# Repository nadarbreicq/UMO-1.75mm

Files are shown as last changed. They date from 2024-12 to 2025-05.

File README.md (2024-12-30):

# UMO-1.75mm

The Ultimaker Original, released in 2011, was my first personal 3D printer. I received it at the end of 2012 and used it without major issues until 2020. However, after that, several challenges arose:

- All my other printers used 1.75 mm filament, and I no longer wanted to manage two separate filament stocks due to insufficient throughput.
- The hotend of my Ultimaker Original started to show its age, and high-quality replacement parts were either unavailable or too expensive.
- The extruder had become almost unusable and suffered from the same supply issues as the hotend.
- Determined to keep this fantastic machine running—still capable, I’m sure, of producing quality prints—I decided to modify it to use standard Ender 3 parts and transition to 1.75 mm filament.

The goal of this repository is to share this journey with you and maybe even inspire you to try it yourself if you're interested! 😊

*This project is still a Work in Progress.*

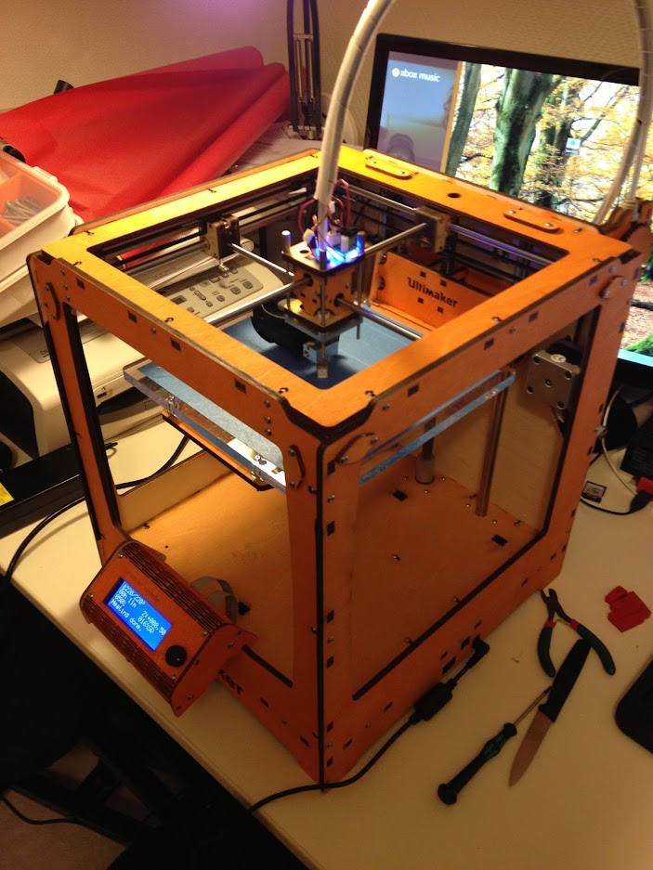
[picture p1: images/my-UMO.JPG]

*My Ultimaker Original in early 2013*

---

## **Bill of Materials (BOM)**

To modify my Ultimaker, I used the materials listed below. They are fairly standard and readily available online.

- **Extruder**: [Product Link](https://www.amazon.fr/dp/B09H6T3NNT?ref=ppx_yo2ov_dt_b_fed_asin_title&th=1)
- **HotEnd**: [Product Link](https://www.amazon.fr/dp/B09RXRQ5HM?ref=ppx_yo2ov_dt_b_fed_asin_title&th=1)

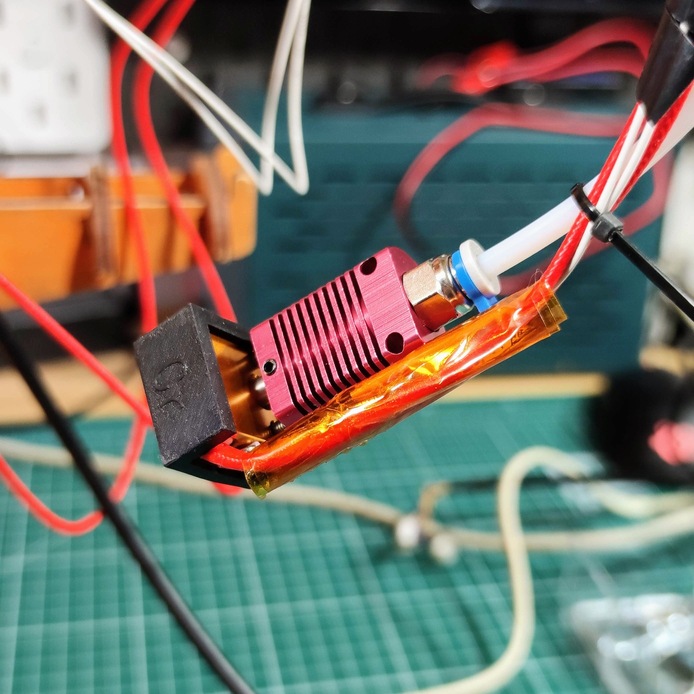
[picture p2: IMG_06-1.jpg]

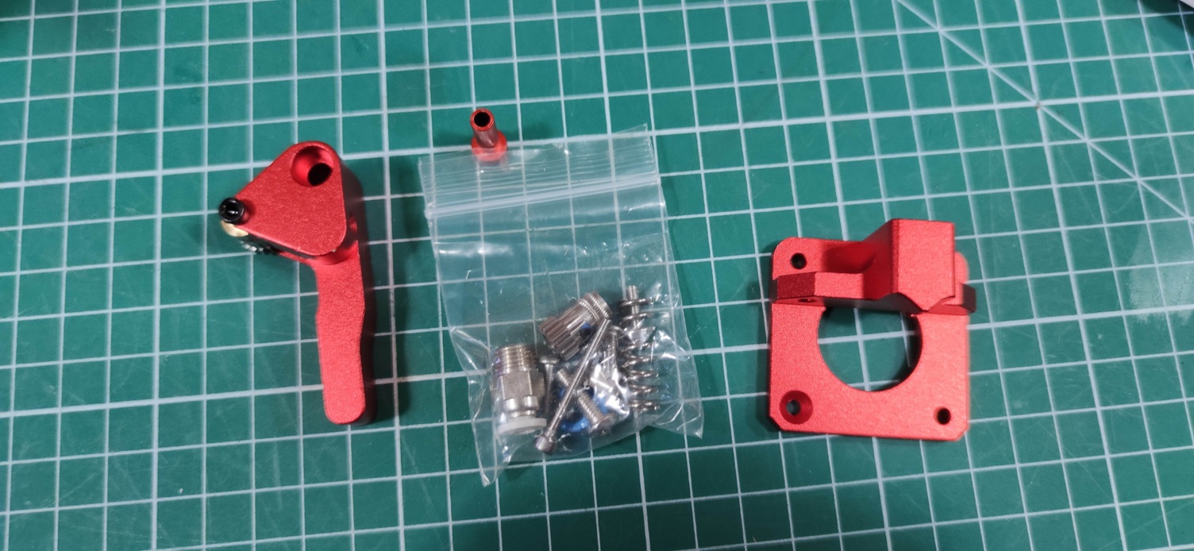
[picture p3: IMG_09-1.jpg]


You will also need a 40x40 fan to cool the print head and prevent clogging in the PTFE tube. In my case, I had a fan from an Ender 2 Pro among my spare parts, but any fan of the same type will work.

You will also need a 4.7K ohm resistor to solder onto the board (along with a soldering iron) and Molex KK254 connectors if you prefer not to cut and modify the existing sensor cable.

Regarding the resistor, it is recommended to use a high-precision resistor if you want to improve the accuracy of temperature readings. However, for initial testing, a resistor with 5% tolerance will do the job. It will be soldered to the **R23** position on the mainboard.

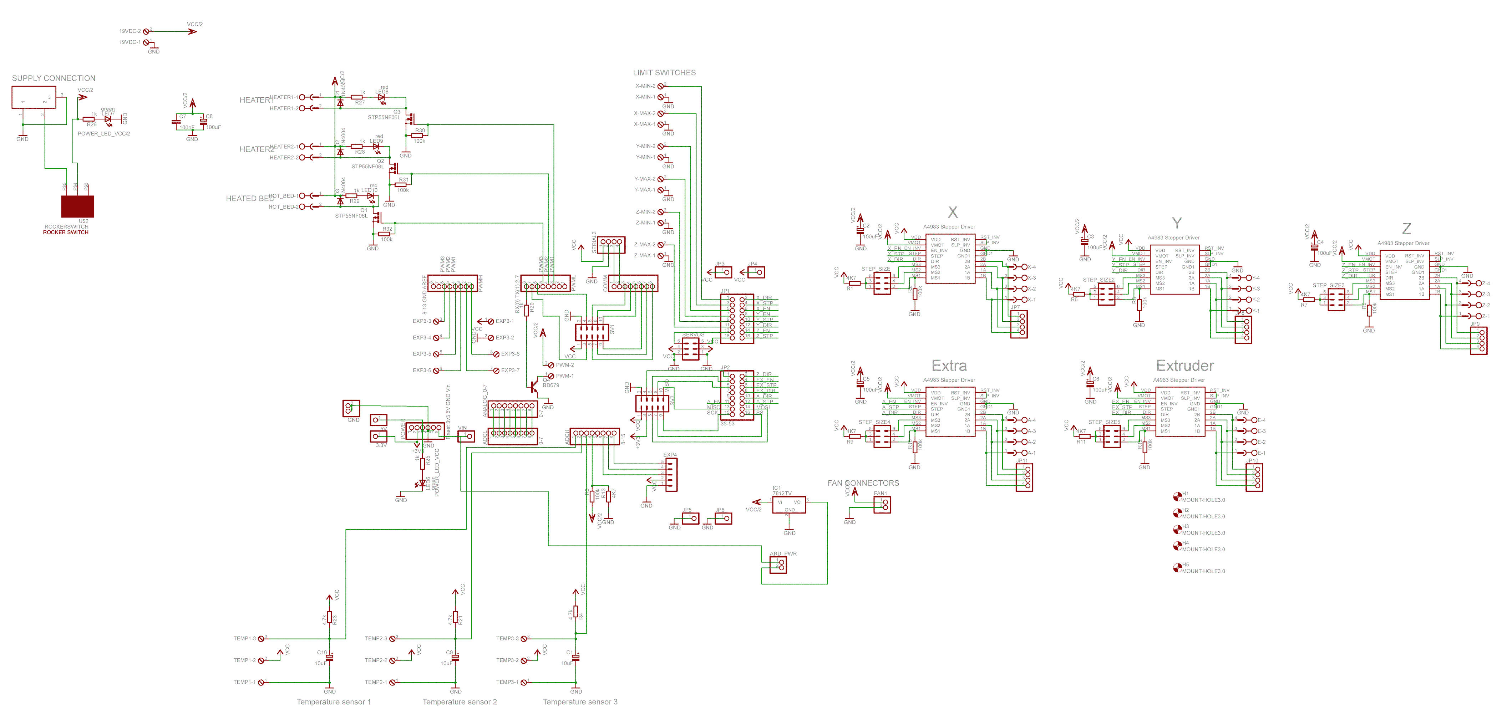
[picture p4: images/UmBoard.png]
Board Diagram


To help you, you can also take a look at the BOM from Ultimaker Repo :

- Original files from ultimaker : [Ultimaker Original BOM](https://github.com/Ultimaker/UltimakerOriginal/tree/master)

---

### **Removing the Original Print Head and Extruder**

**Note:** In my case, I had already attempted a modification of the extruder. The version I have is therefore slightly different. I’ll use this version to temporarily attach the new extruder while I design a proper *Ultimaker-style* replacement.

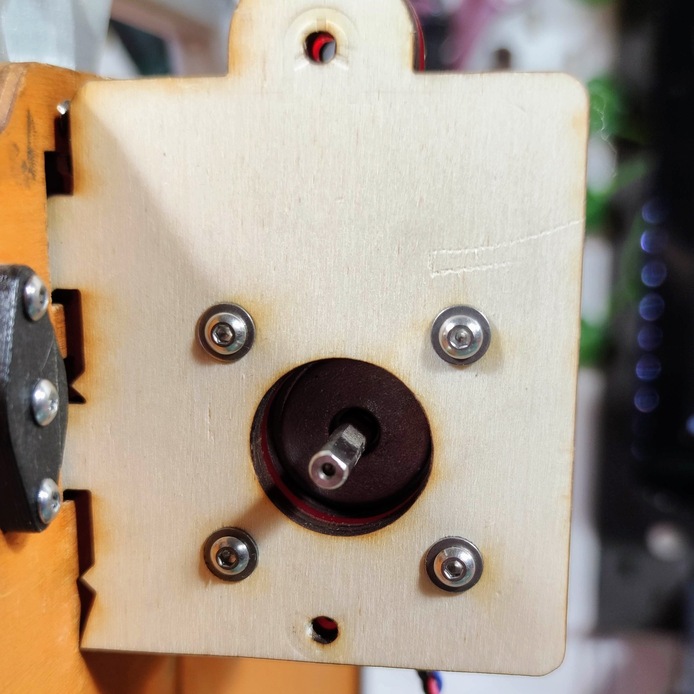
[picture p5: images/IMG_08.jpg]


#### **Steps to Disassemble the Print Head**

1. **Disconnect the heater cartridge wires**:
   
   Begin by unscrewing the connections for the heater cartridge from the mainboard. Keep the existing sensor cable intact, as it will later be repurposed for the print fan. While you're at it, disconnect the temperature sensor wires as well.

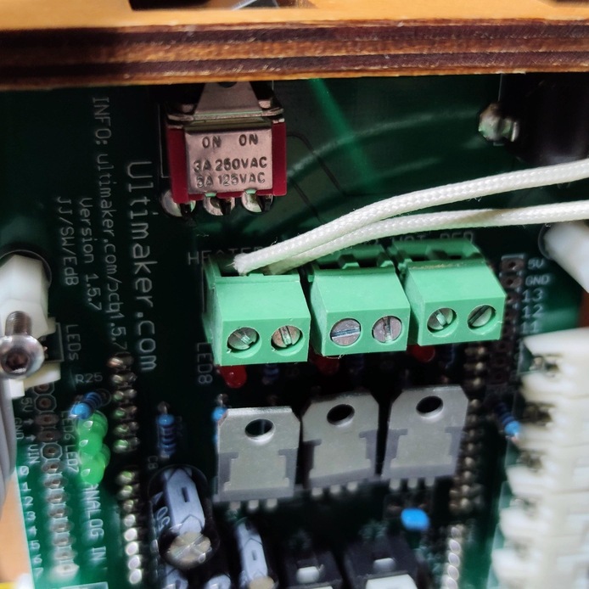
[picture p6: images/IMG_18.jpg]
  
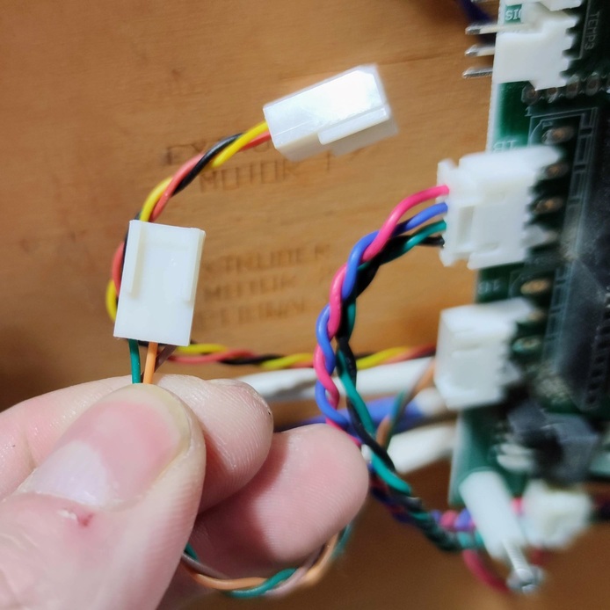
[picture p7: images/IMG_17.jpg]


2. **Remove the print head carefully**:
   
   You can now cautiously disassemble the print head. Be sure to keep all components, as you might want to reassemble them later. In my case, I decided to take everything apart individually because I wasn’t sure how the reassembly would go. Initially, I planned to reuse the original heater cartridge and sensor.  

   Unfortunately, the head was in such poor condition that this became impossible, and the head connector broke into two pieces.  

   **Pro Tip:** Try to handle the disassembly more neatly than I did! 😊

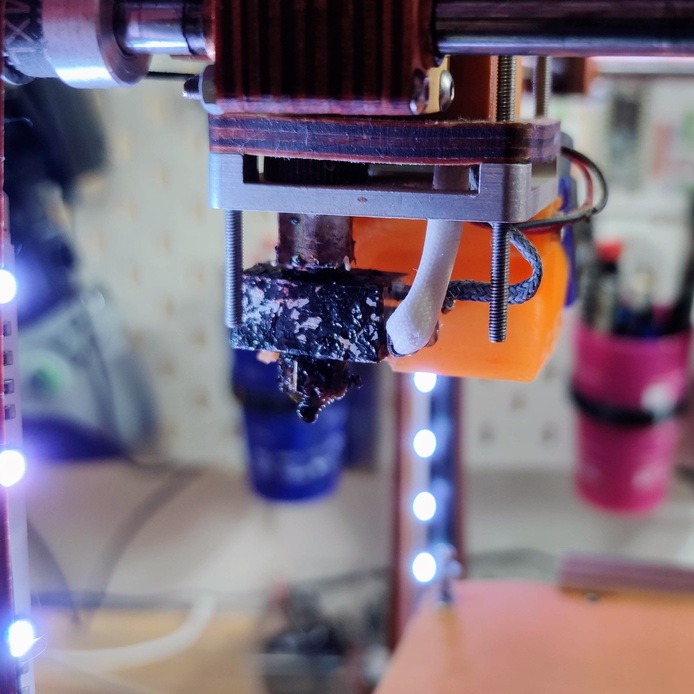
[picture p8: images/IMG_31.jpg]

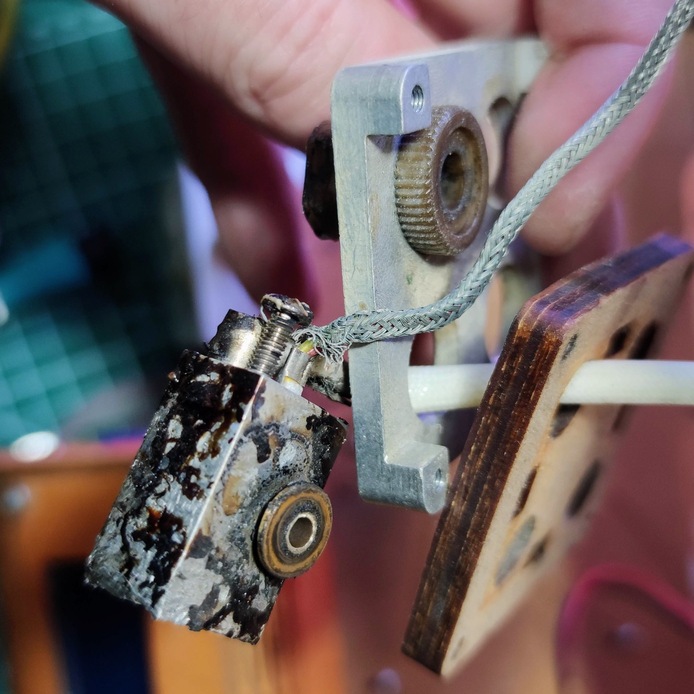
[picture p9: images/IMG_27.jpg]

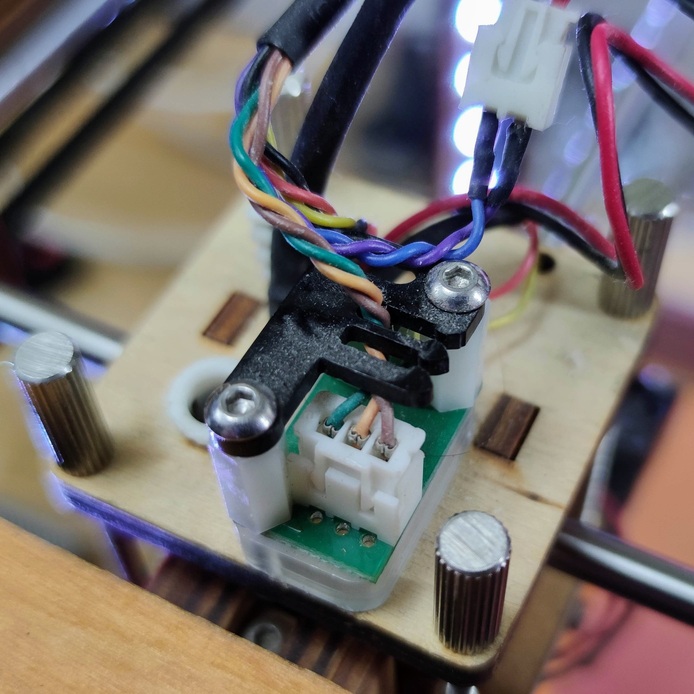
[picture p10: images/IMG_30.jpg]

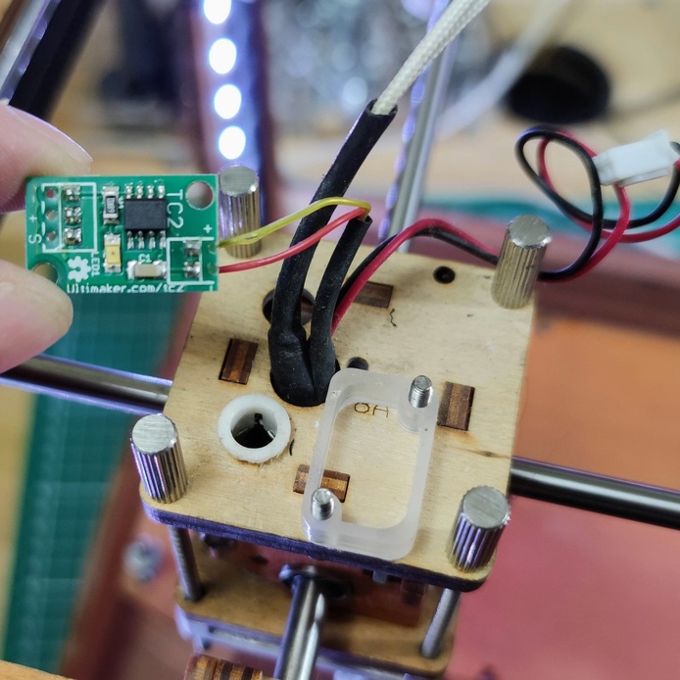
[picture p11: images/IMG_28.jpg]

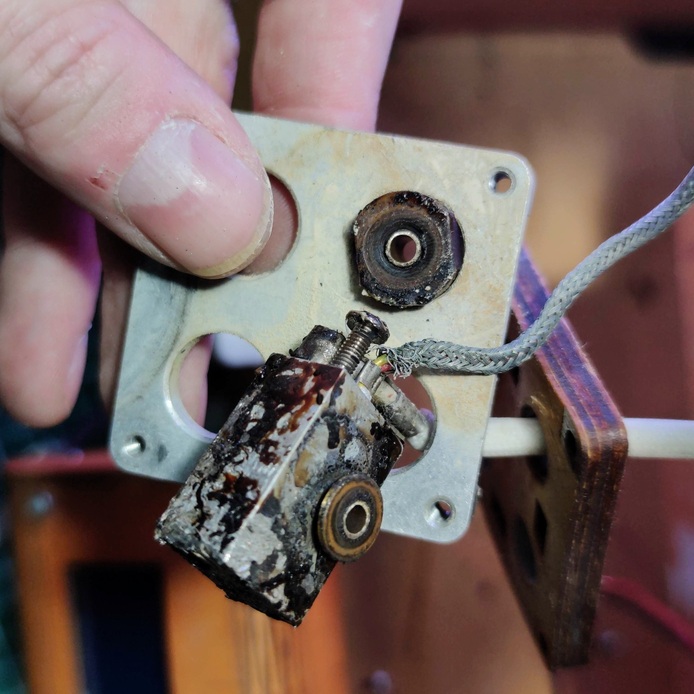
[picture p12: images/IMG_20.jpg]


#### **Assembling the Extruder**

In this case, there isn’t much to explain. The motor is compatible with the extruder, making the modification relatively straightforward. You’ll just need a mounting plate to secure the assembly. The original plate will do the job if you still have it.


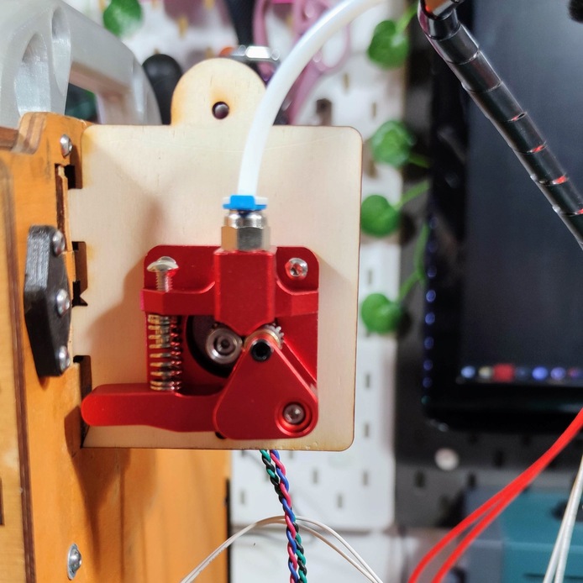
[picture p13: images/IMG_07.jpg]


#### **Cable Routing**

Now, route all the cables from the new print head through the original cable path. You should have two wires for the heater cartridge and two wires for the temperature sensor.



**Note:** I’ve always been a bit skeptical about the cable routing and cable management on this machine. While using nylon fabric sleeves for the cable bundle is a great idea, the management underneath is a real mess. 😅 I’ll have to address it properly one of these days.

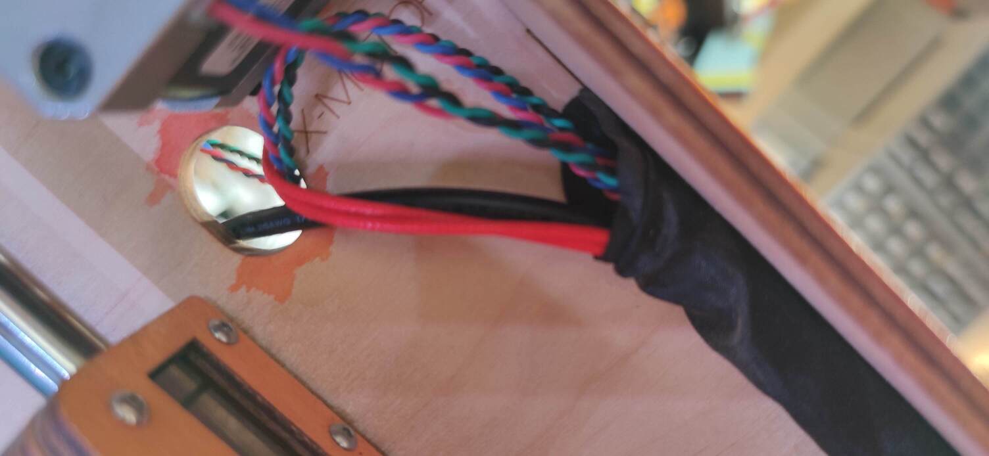
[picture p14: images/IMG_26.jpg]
  
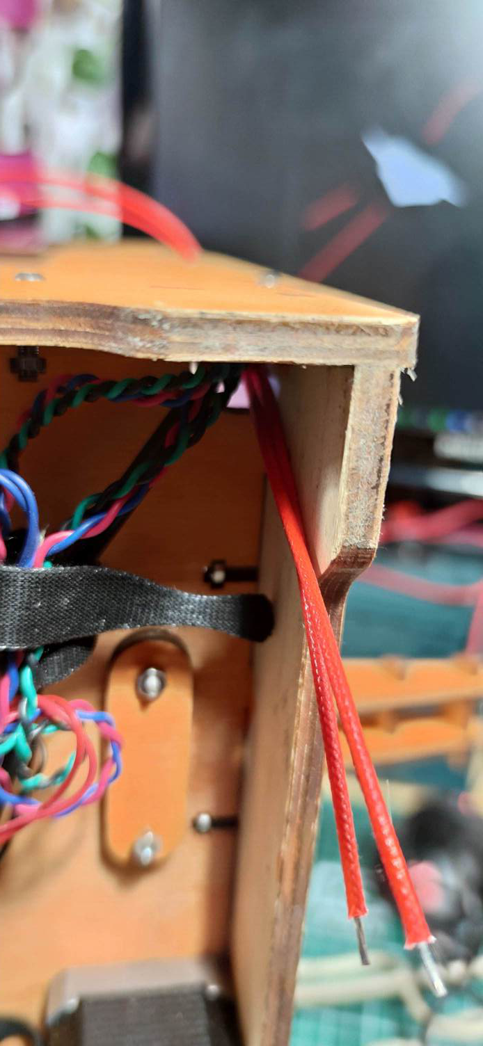
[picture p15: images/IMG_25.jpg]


Connect the heater cartridge wires to the same spot on the board as the original cartridge. The polarity doesn’t matter.  

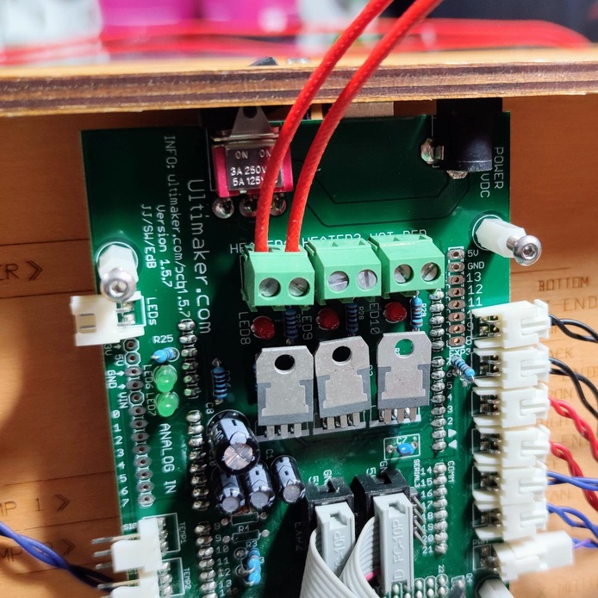
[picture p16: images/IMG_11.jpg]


#### **Soldering the 4.7K Resistor**

Next, solder the 4.7K ohm resistor. If you’re feeling ambitious, you can unplug everything, remove the board, and solder the resistor "properly" through the PCB. However, for initial testing, you can shape the resistor as shown in the photo and solder it "on the surface." This approach is fine for now, especially if you're using a 5% tolerance resistor and plan to replace it later with a more precise one.

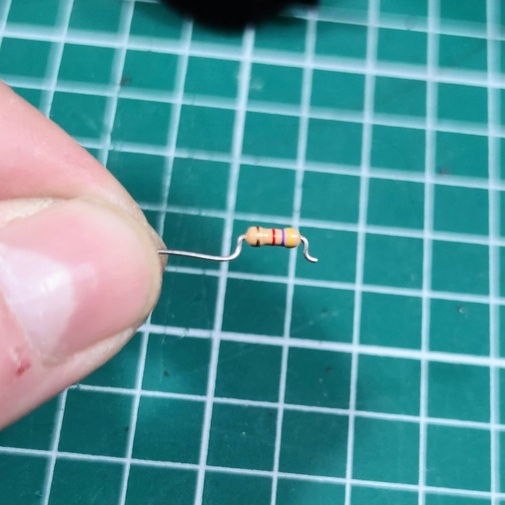
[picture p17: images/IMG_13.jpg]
  
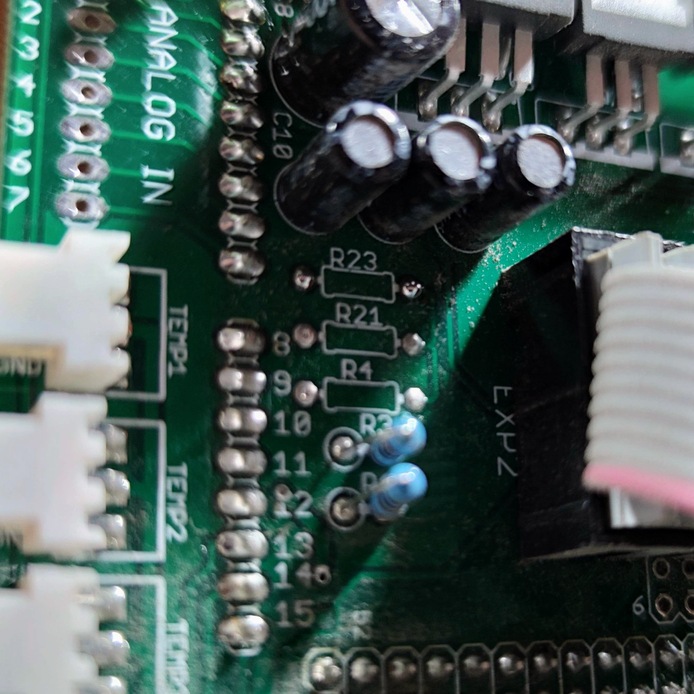
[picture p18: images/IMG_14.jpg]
  
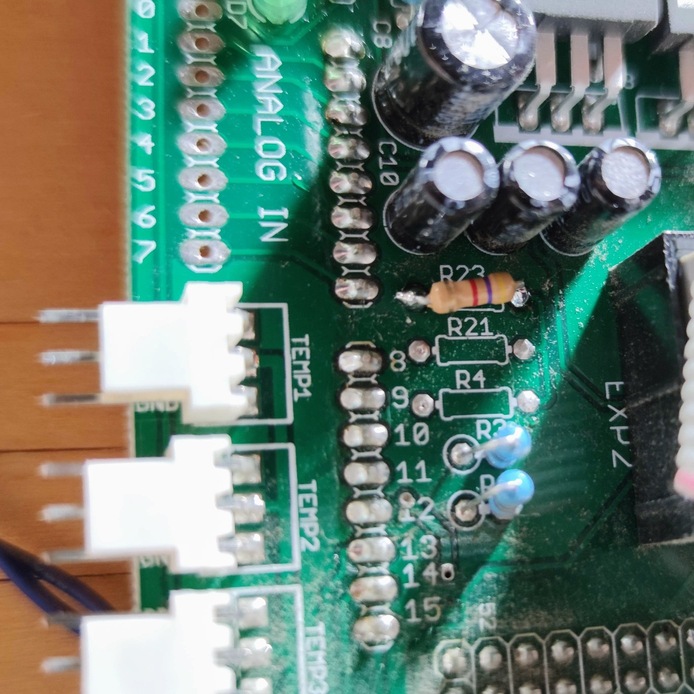
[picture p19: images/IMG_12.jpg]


#### **Creating a Sensor Connector**

Next, create a connector for the temperature sensor. Use a Molex KK254 connector and connect the sensor to the **GND** and **SIG** pins at the ends. Then, plug the connector into the board at the **TEMP1** slot.

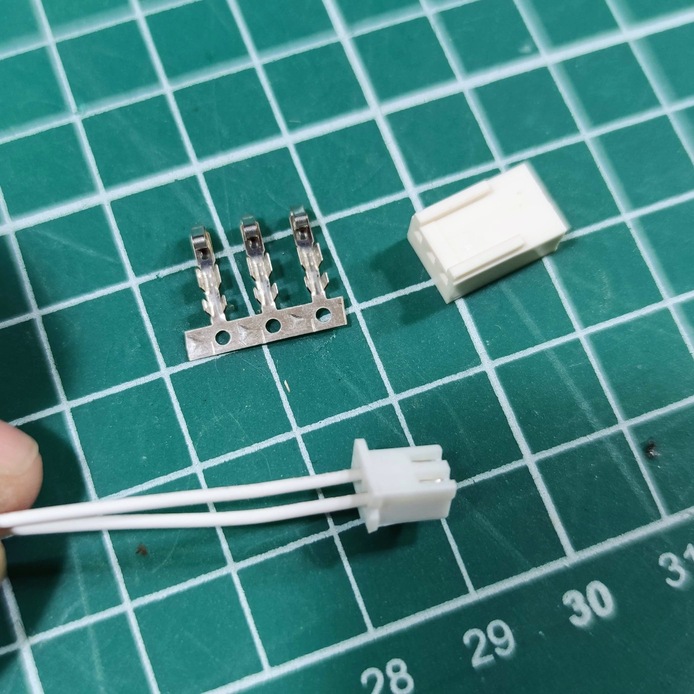
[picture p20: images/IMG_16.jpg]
  
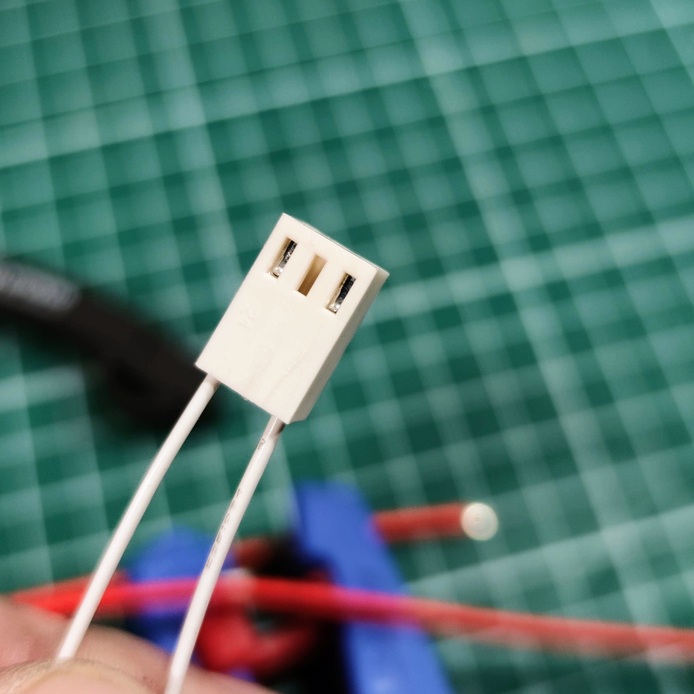
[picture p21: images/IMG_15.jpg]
  
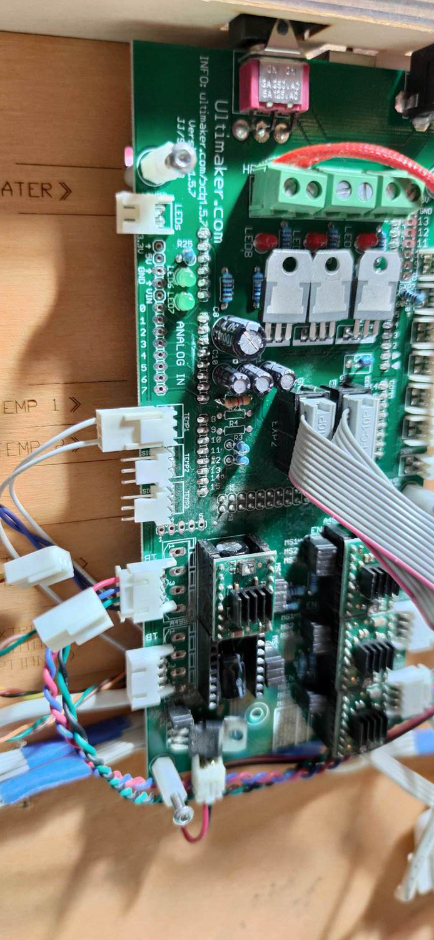
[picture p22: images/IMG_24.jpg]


#### **Adding the Print Head Fan**

This wasn’t a feature on the original machines, but later on, cooling the hotend became essential to prevent filament clogging. For this, you can use a 40x40 mm 24V fan and connect it to the cooling fan port on the board. Since the fan needs to be always on, there’s no need for a specific input.  

Take advantage of having the board accessible to complete this connection and route your fan cables.  

**NOTE:** I didn’t take photos of this step but will add them later.  

#### **Test Assembly**

If you have leftover parts, you can set up a temporary assembly, as I did, to test your connections. In this case, I used some old parts from an Ender 2 Pro to mount the fan and the print head for initial tests.

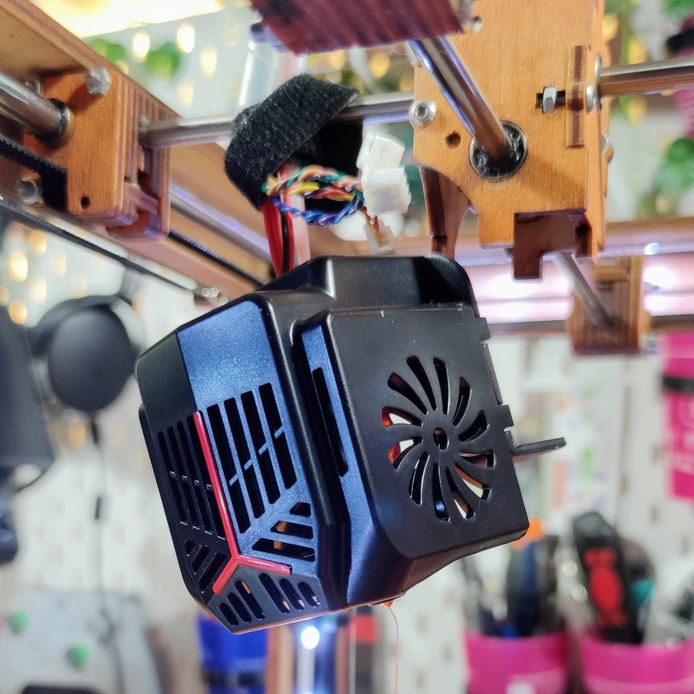
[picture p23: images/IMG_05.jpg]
  

---

## **Compiling Marlin Firmware**

Use **Arduino IDE 1.x** to compile and flash Marlin.

### Changes in `Configuration.h`:

- Configure the temperature sensor:
  ```c
  #define TEMP_SENSOR_0 1 
  // 1 is a 100k thermistor - ideal for EPCOS 100k (with a 4.7k pullup resistor)
  ```

---

## **Temperature Tests**

Before proceeding, test the temperature sensor functionality:

1. Send the following command via a G-code terminal:
   ```gcode
   M109 S50
   ```
2. Check if the temperature increases when the hotend is heated.

---

## **Hotend PID Calibration**

Perform PID auto-tuning to optimize heating performance:

1. Run the following command:
   ```gcode
   M303 E0 S200 C8
   ```
2. Record the results (Kp, Ki, Kd). For example:
   ```
   Kp: 47.02
   Ki: 5.48
   Kd: 100.91
   ```
3. Update these values in `Configuration.h`:
   ```c
   #define DEFAULT_Kp 47.02
   #define DEFAULT_Ki 5.48
   #define DEFAULT_Kd 100.91
   ```

---

## **Setting Steps per mm (e-steps)**

Calibrate the extruder to ensure proper extrusion:

1. Set the e-steps value. For me, the value was:
   ```gcode
   M92 E140
   M500
   ```
   > **Note**: Adjust this value according to your setup if needed.

2. Test the extruder movement:
   - Extrude 10 mm of filament:
     ```gcode
     G1 E10 F100
     ```
   - Retract 10 mm:
     ```gcode
     G1 E-10 F800
     ```

---

## **Important Notes**

- Ensure the hotend is properly heated before extruding or retracting filament.

---

With these steps, your Ultimaker Original is ready to work with 1.75 mm filaments. If you encounter any issues or have questions, feel free to share your experience!

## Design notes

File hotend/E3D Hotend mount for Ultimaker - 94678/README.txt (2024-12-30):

E3D Hotend mount for Ultimaker by am001 on Thingiverse: https://www.thingiverse.com/thing:94678

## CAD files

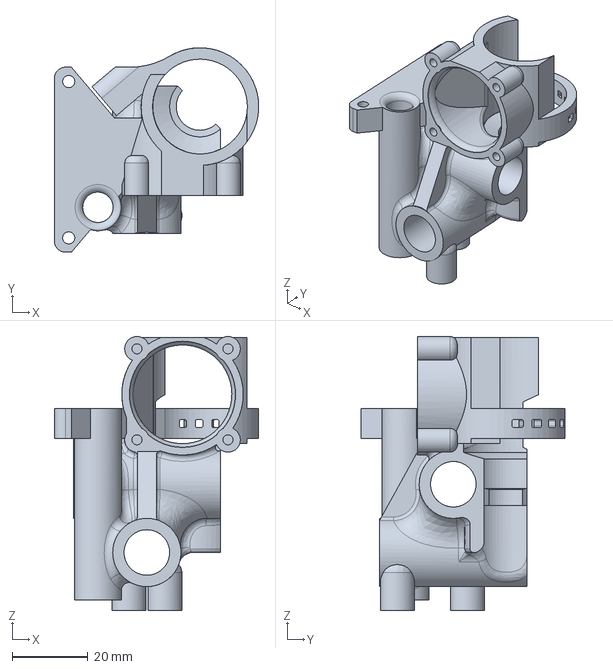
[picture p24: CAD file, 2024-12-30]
hotend/E3D Hotend mount for Ultimaker - 94678/E3D-Ultimaker-Orginal file from am001.stp
53.9 x 53.9 x 72.2 mm

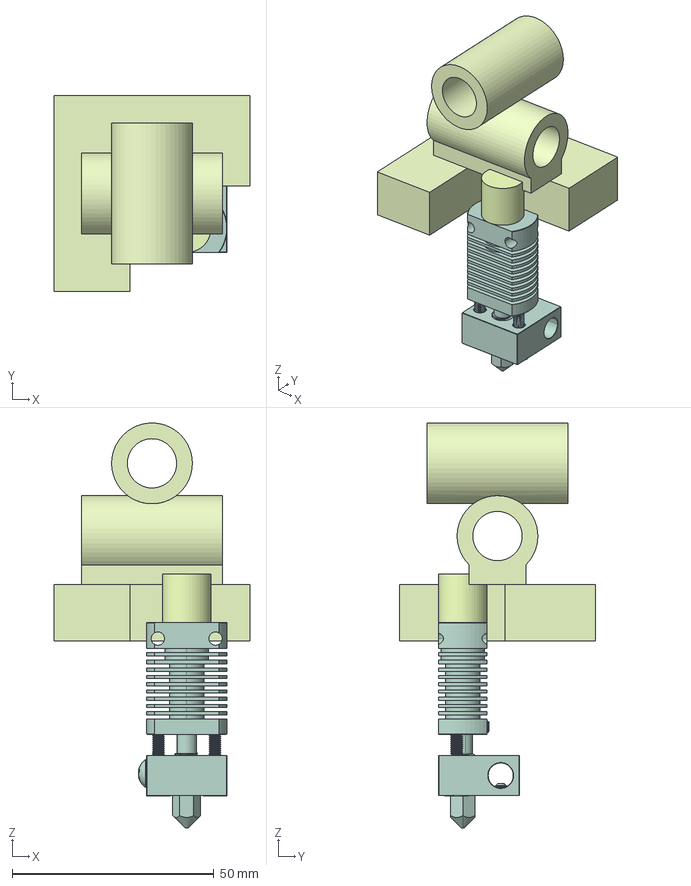
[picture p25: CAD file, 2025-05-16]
hotend/hotend-UMO-1_75-V2.FCStd
48.5 x 48.5 x 100.3 mm
Hotend-UMO-Ender3
HotEnd

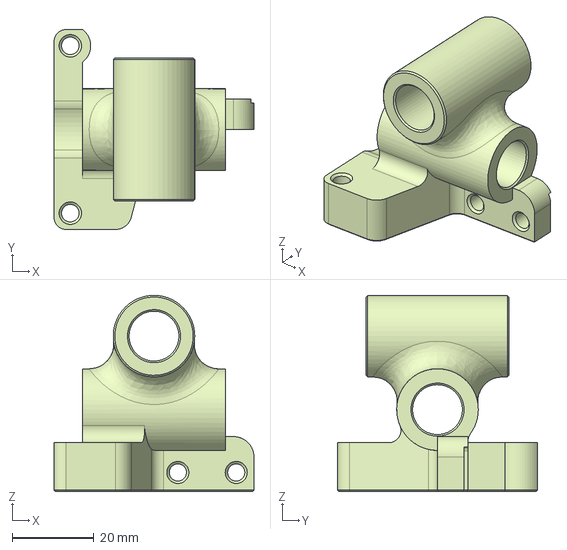
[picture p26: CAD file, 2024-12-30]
hotend/hotend-UMO-1_75.step
49.0 x 49.0 x 48.1 mm

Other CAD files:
hotend/hotend-UMO-1_75.3mf
hotend/hotend-UMO-1_75.FCStd
hotend/hotend-UMO-1_75.stl

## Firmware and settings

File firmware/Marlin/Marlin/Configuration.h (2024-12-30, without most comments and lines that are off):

#define CONFIGURATION_H
#define STRING_VERSION_CONFIG_H __DATE__ " " __TIME__ // build date and time
#define STRING_CONFIG_H_AUTHOR "(David Braam)" //Who made the changes.
#define VERSION_BASE    "Ultimaker: DEV"
#define VERSION_PROFILE "Github checkout"
#define VERSION_STRING  VERSION_BASE " (" VERSION_PROFILE ")"
#define SERIAL_PORT 0
#define BAUDRATE 250000
#define MOTHERBOARD 7
#define EXTRUDERS 1
#define POWER_SUPPLY 1
#define TEMP_SENSOR_0 1
#define TEMP_SENSOR_1 0
#define TEMP_SENSOR_2 0
#define TEMP_SENSOR_BED 0
#define MAX_REDUNDANT_TEMP_SENSOR_DIFF 10
#define TEMP_RESIDENCY_TIME 3	// (seconds)
#define TEMP_HYSTERESIS 3       // (degC) range of +/- temperatures considered "close" to the target one
#define TEMP_WINDOW     1       // (degC) Window around target to start the residency timer x degC early.
#define HEATER_0_MINTEMP 5
#define HEATER_1_MINTEMP 5
#define HEATER_2_MINTEMP 5
#define BED_MINTEMP 5
#define HEATER_0_MAXTEMP 275
#define HEATER_1_MAXTEMP 275
#define HEATER_2_MAXTEMP 275
#define BED_MAXTEMP 150
#define PIDTEMP
#define BANG_MAX 255 // limits current to nozzle while in bang-bang mode; 255=full current
#define PID_MAX 255 // limits current to nozzle while PID is active (see PID_FUNCTIONAL_RANGE below); 255=full current
  #define PID_FUNCTIONAL_RANGE 10 // If the temperature difference between the target temperature and the actual temperature
  #define PID_INTEGRAL_DRIVE_MAX 255  //limit for the integral term
  #define K1 0.95 //smoothing factor within the PID
  #define PID_dT ((OVERSAMPLENR * 8.0)/(F_CPU / 64.0 / 256.0)) //sampling period of the temperature routine
    #define  DEFAULT_Kp 47.02
    #define  DEFAULT_Ki 5.48
    #define  DEFAULT_Kd 100.91
#define MAX_BED_POWER 255 // limits duty cycle to bed; 255=full current
#define PREVENT_DANGEROUS_EXTRUDE
#define PREVENT_LENGTHY_EXTRUDE
#define EXTRUDE_MINTEMP 170
#define EXTRUDE_MAXLENGTH (X_MAX_LENGTH+Y_MAX_LENGTH) //prevent extrusion of very large distances.
#define ENDSTOPPULLUPS // Comment this out (using // at the start of the line) to disable the endstop pullup resistors
  #define ENDSTOPPULLUP_XMAX
  #define ENDSTOPPULLUP_YMAX
  #define ENDSTOPPULLUP_ZMAX
  #define ENDSTOPPULLUP_XMIN
  #define ENDSTOPPULLUP_YMIN
  #define ENDSTOPPULLUP_ZMIN
const bool X_MIN_ENDSTOP_INVERTING = true; // set to true to invert the logic of the endstop.
const bool Y_MIN_ENDSTOP_INVERTING = true; // set to true to invert the logic of the endstop.
const bool Z_MIN_ENDSTOP_INVERTING = true; // set to true to invert the logic of the endstop.
const bool X_MAX_ENDSTOP_INVERTING = true; // set to true to invert the logic of the endstop.
const bool Y_MAX_ENDSTOP_INVERTING = true; // set to true to invert the logic of the endstop.
const bool Z_MAX_ENDSTOP_INVERTING = true; // set to true to invert the logic of the endstop.
#if defined(COREXY) && !defined(DISABLE_MAX_ENDSTOPS)
  #define DISABLE_MAX_ENDSTOPS
#endif
#define X_ENABLE_ON 0
#define Y_ENABLE_ON 0
#define Z_ENABLE_ON 0
#define E_ENABLE_ON 0 // For all extruders
#define DISABLE_X false
#define DISABLE_Y false
#define DISABLE_Z false
#define DISABLE_E false // For all extruders
#define INVERT_X_DIR true    // for Mendel set to false, for Orca set to true
#define INVERT_Y_DIR false    // for Mendel set to true, for Orca set to false
#define INVERT_Z_DIR true     // for Mendel set to false, for Orca set to true
#define INVERT_E0_DIR false   // for direct drive extruder v9 set to true, for geared extruder set to false
#define INVERT_E1_DIR false    // for direct drive extruder v9 set to true, for geared extruder set to false
#define INVERT_E2_DIR false   // for direct drive extruder v9 set to true, for geared extruder set to false
#define X_HOME_DIR -1
#define Y_HOME_DIR -1
#define Z_HOME_DIR -1
#define min_software_endstops false //If true, axis won't move to coordinates less than HOME_POS.
#define max_software_endstops false  //If true, axis won't move to coordinates greater than the defined lengths below.
#define X_MAX_POS 205
#define X_MIN_POS 0
#define Y_MAX_POS 205
#define Y_MIN_POS 0
#define Z_MAX_POS 200
#define Z_MIN_POS 0
#define X_MAX_LENGTH (X_MAX_POS - X_MIN_POS)
#define Y_MAX_LENGTH (Y_MAX_POS - Y_MIN_POS)
#define Z_MAX_LENGTH (Z_MAX_POS - Z_MIN_POS)
#define MANUAL_X_HOME_POS 0
#define MANUAL_Y_HOME_POS 0
#define MANUAL_Z_HOME_POS 0
#define NUM_AXIS 4 // The axis order in all axis related arrays is X, Y, Z, E
#define HOMING_FEEDRATE {50*60, 50*60, 4*60, 0}  // set the homing speeds (mm/min)
#define DEFAULT_AXIS_STEPS_PER_UNIT   {78.7402,78.7402,200.0*8/3,760*1.1}  // default steps per unit for Ultimaker
#define DEFAULT_MAX_FEEDRATE          {500, 500, 5, 25}    // (mm/sec)
#define DEFAULT_MAX_ACCELERATION      {9000,9000,100,10000}    // X, Y, Z, E maximum start speed for accelerated moves. E default values are good for Skeinforge 40+, for older versions raise them a lot.
#define DEFAULT_ACCELERATION          4000    // X, Y, Z and E max acceleration in mm/s^2 for printing moves
#define DEFAULT_RETRACT_ACCELERATION  3000   // X, Y, Z and E max acceleration in mm/s^2 for retracts
#define DEFAULT_XYJERK                20.0    // (mm/sec)
#define DEFAULT_ZJERK                 0.4     // (mm/sec)
#define DEFAULT_EJERK                 5.0    // (mm/sec)
#define CUSTOM_M_CODES
  #define CUSTOM_M_CODE_SET_Z_PROBE_OFFSET 851
  #define Z_PROBE_OFFSET_RANGE_MIN -15
  #define Z_PROBE_OFFSET_RANGE_MAX -5
#define EEPROM_SETTINGS
#define EEPROM_CHITCHAT
#define PLA_PREHEAT_HOTEND_TEMP 210
#define PLA_PREHEAT_HPB_TEMP 70
#define PLA_PREHEAT_FAN_SPEED 0		// Insert Value between 0 and 255
#define ABS_PREHEAT_HOTEND_TEMP 250
#define ABS_PREHEAT_HPB_TEMP 100
#define ABS_PREHEAT_FAN_SPEED 0		// Insert Value between 0 and 255
#define ULTIMAKERCONTROLLER //as available from the Ultimaker online store.
 #define ULTIPANEL
 #define NEWPANEL
  #define SDSUPPORT
  #define ULTRA_LCD
    #define LCD_WIDTH 20
    #define LCD_HEIGHT 4
#define FAST_PWM_FAN
#define SOFT_PWM_SCALE 0
#include "Configuration_adv.h"
#include "thermistortables.h"

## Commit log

2024-12-30 Create Ultimaker Original 0.4 nozzle - 1.75mm.orca_printer
2024-12-30 Update Ultimaker Original 0.4 nozzle - 1.75mm.orca_printer
2025-05-16 live 225 - WIP
    [hotend-UMO-1_75-V2.FCStd]
